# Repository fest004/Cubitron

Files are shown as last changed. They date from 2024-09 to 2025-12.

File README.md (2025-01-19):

```
   ▄█   ▄█▄ ███    █▄  ▀█████████▄     ▄████████ ███▄▄▄▄   
  ███ ▄███▀ ███    ███   ███    ███   ███    ███ ███▀▀▀██▄ 
  ███▐██▀   ███    ███   ███    ███   ███    █▀  ███   ███ 
 ▄█████▀    ███    ███  ▄███▄▄▄██▀   ▄███▄▄▄     ███   ███ 
▀▀█████▄    ███    ███ ▀▀███▀▀▀██▄  ▀▀███▀▀▀     ███   ███ 
  ███▐██▄   ███    ███   ███    ██▄   ███    █▄  ███   ███ 
  ███ ▀███▄ ███    ███   ███    ███   ███    ███ ███   ███ 
  ███   ▀█▀ ████████▀  ▄█████████▀    ██████████  ▀█   █▀  
  ▀                                                        
```
#### You can read about it here: [Link to documentation](https://fest004.github.io/Cubitron/)

#### Folder structure

```
.
├── docs             # Documents (datasheets, references, documentation)
├── hardware         # Hardware design files (CAD)
├── software         # Software files (source files, build files and binaries)
├── LICENSE
└── README.md
```

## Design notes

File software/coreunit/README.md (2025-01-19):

This folder contains the firmware for the main microcontroller

#### Folder structure

```
.
├── docs             # Documents (datasheets, references, documentation)
├── hardware         # Hardware design files (CAD)
├── software         # Software files (source files, build files and binaries)
├── LICENSE
└── README.md
```

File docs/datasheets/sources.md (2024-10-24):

Here is a collection of not datasheets, but external sources/inspiration for some designs.

This github page helped me set up USB-interface with our programmer: 
https://github.com/wagiminator/SAMD-Development-Boards/blob/main/SAMD11D_DevBoard/hardware/SAMD11D_DevBoard_schematic.pdf

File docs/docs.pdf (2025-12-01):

# KUBEN

# 3-Axis Balancing Cube

Hardware Revision 1.0

# 1 • ABOUT THE PROJECT

This document outlines the electrical and mechanical architecture for a 15cm³ self-balancing reaction wheel robot. The system utilizes Model Predictive Control (MPC) or Linear Quadratic Regulation (LQR) to handle the coupled dynamics of three orthogonal axes.

Specs
- Dimensions: 15cm × 15cm × 15cm
- Power Source: 4S LiPo (16.8V Peak)
- Peak Current: 12A (4A per motor)

Key Components
- Compute: ESP32
- Motor Driver: DRV
- Sensor: IMU

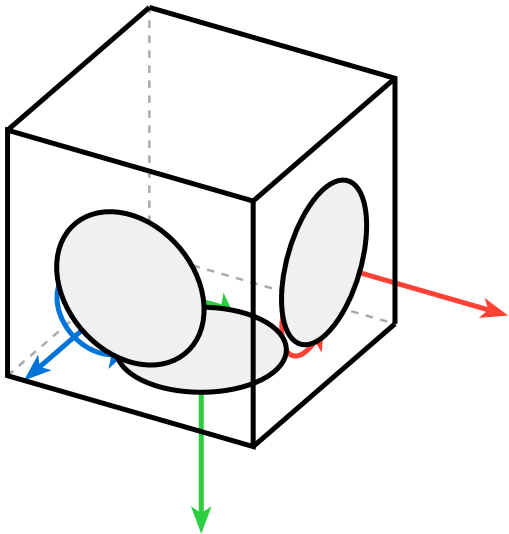
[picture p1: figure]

Figure 1: sketch

# CONTENTS

# 2 • SYSTEM ARCHITECTURE

The system is designed around a centralized controller (ESP32-S3) that manages three motor drivers via SPI and PWM. The control loop runs on a dedicated core to ensure real-time performance for the MPC solver.

## 2.1 • HIGH-LEVEL BLOCK DIAGRAM

- Inputs: IMU (SPI), Encoders (Quadrature), Battery Voltage (ADC).
- Processing: ESP32-S3-WROOM-1 Module.
- Outputs: 3x PWM signals (U, V, W) to Gate Drivers.
- Actuation: 3x BLDC Motors (Gimbal Type) via DRV8316.

DRV8316

DRV8316

DRV8316

MOTOR

MOTOR

MOTOR

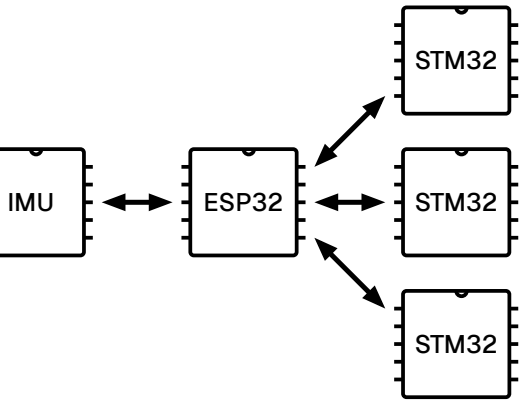
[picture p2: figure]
IMU; ESP32; STM32

Figure 2: block diagram of the controll circuit

# 3 • ELECTRONICS DESIGN

The PCB is a custom 4-layer board designed for high vibration resistance and thermal dissipation.

## 3.1 • MICROCONTROLLER SELECTION

Component: ESP32-S3-WROOM-1-N8R8
- Form Factor: Surface Mount Module (Castellated).
- Reasoning: Through-hole headers fail under reaction wheel vibration. The module provides robust mechanical coupling and optimal center of mass.
- Peripherals Used: - 3x PCNT (Hardware Encoder Counters)
- 2x MCPWM (Motor Control PWM)
- ADC1 (Current Sensing - ADC2 is avoided due to WiFi conflict)

## 3.2 • 3.2. PIN MAPPING (ESP32-S3)

Critical: Do not route current sensing to ADC2. Do not pull strapping pins (GPIO 0, 45, 46) high during boot.

Function | Signal | GPIO | Note
Motor X | PWM U/V/W | 14, 15, 16 | MCPWM Unit 0
| Current Sense | 1 | ADC1_CH0 (Strict requirement)
| Encoder A/B | 38, 39 | PCNT Unit 0
Motor Y | PWM U/V/W | 17, 18, 21 | MCPWM Unit 0
| Current Sense | 2 | ADC1_CH1
| Encoder A/B | 40, 41 | PCNT Unit 1
Motor Z | PWM U/V/W | 35, 36, 37 | MCPWM Unit 1
| Current Sense | 3 | ADC1_CH2
| Encoder A/B | 42, 43 | PCNT Unit 2
Shared | IMU SPI (SCK/MI/MO) | 12, 13, 11 | LSM6DSO Connection
| Driver nSLEEP | 4 | Active High to wake drivers
| Battery Sense | 7 | ADC1_CH6 (Voltage Divider)

Table 1: Master Pin Assignment Table

## 3.3 • 3.3. MOTOR DRIVERS (TI DRV8316)

Variant: DRV8316R (Hardware) or DRV8316T (SPI). SPI is preferred for adjustable gain.
- Current Sensing: The chip has internal Current Sense Amplifiers (CSA) but no internal ADC.
- Wiring Requirement: The SO1, SO2, SO3 pins must be routed to the ESP32 ADC pins listed above.
- Mode: Operate in Current Sense Mode (VREF = 3.3V). Do not use the hardware “Current Limiting Mode” or the torque control will fight the MPC solver.

## 3.4 • 3.4. POWER REGULATION STRATEGY

Direct 16.8V to 3.3V conversion is thermally impossible for the ESP32 load.
1. Stage 1 (Buck): TPS54302 converts 16.8V → 5.0V.
2. Stage 2 (LDO): AMS1117-3.3 converts 5.0V → 3.3V (Clean logic power).

# 4 • 4. SAFETY & PROTECTION CIRCUITS

Reaction wheels generate massive regenerative currents when braking. Protection is mandatory.

## 4.1 • 4.1. REVERSE POLARITY PROTECTION

Component: P-Channel MOSFET (e.g., AO4407).
- Circuit: Gate to GND, Source to Battery+, Drain to System.
- Why: Low voltage drop (<0.1V) compared to diodes, prevents explosion if battery is plugged in backwards.

## 4.2 • 4.2. REGENERATIVE BRAKING CLAMP

Passive: 1000µF 35V Electrolytic Capacitor at the main power entry.
- Active (Optional): If voltage > 18V, a comparator triggers an N-FET to dump energy into a 10Ω, 50W resistor.

## 4.3 • 4.3. BATTERY MANAGEMENT (BMS)

Module: Generic 4S 20A BMS (HX-4S-A01).
- Function: Prevents cell under-voltage (<3.0V) and short circuits.
- Placement: Located between the LiPo battery and the Main PCB.

# 5 • 5. CONTROL THEORY (MPC IMPLEMENTATION)

## 5.1 • 5.1. STATE SPACE MODEL

The robot is modeled as a coupled system. The state vector x contains 9 elements:

### x = [θx

, θy

, θz
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
, ωwx

, ωwy

, ωwz]

T

Where:
- θ: Cube orientation angle (Euler or Quaternion error). •

̇
θ: Angular velocity of the cube (Gyro data).
- ωw: Angular velocity of the reaction wheels (Encoder data).

## 5.2 • 5.2. CONTROL LAW

We utilize an LQR approach for the balancing loop:

### u(t) = −K ⋅ x(t)

Where K is the optimal gain matrix derived from the system physics (Inertia Tensor) and cost matrices Q and R.

## 5.3 • 5.3. SOFTWARE SANDBOX (SAFETY LIMITS)

To prevent MPC instability (hallucinations) from destroying hardware:
- Max Tilt: If |θ| > 20°, Disable_Motors().
- Max Current: Software clamp at 6A per motor.
- Slew Rate: Limit d(Torque)
d

to prevent mechanical jerking.

# 6 • 6. BILL OF MATERIALS (KEY COMPONENTS)

Component | Part Number | Notes
MCU Module | ESP32-S3-WROOM-1 | N8R8 (8MB Flash/PSRAM) recommended.
Motor Driver | TI DRV8316 | Qty: 3. Requires bottom thermal pad vias.
IMU | ST LSM6DSO | SPI Interface. Mount at PCB center.
Buck Converter | TPS54302 | Steps 16V down to 5V.
Protection FET | AO4407 | P-Channel MOSFET for reverse polarity.
Bulk Cap | 1000µF 35V | Low ESR Electrolytic.
Battery | 4S LiPo 650mAh | High C-rating (45C+).

# 7 • 7. NEXT STEPS

1. Simulation: Model the physics in Python/MATLAB to derive the K matrix.
2. Schematic Capture: Implement the pin map in KiCad/EasyEDA.
3. PCB Layout: Focus on thermal vias for DRV8316 and minimizing loop inductance for the capac-itors.

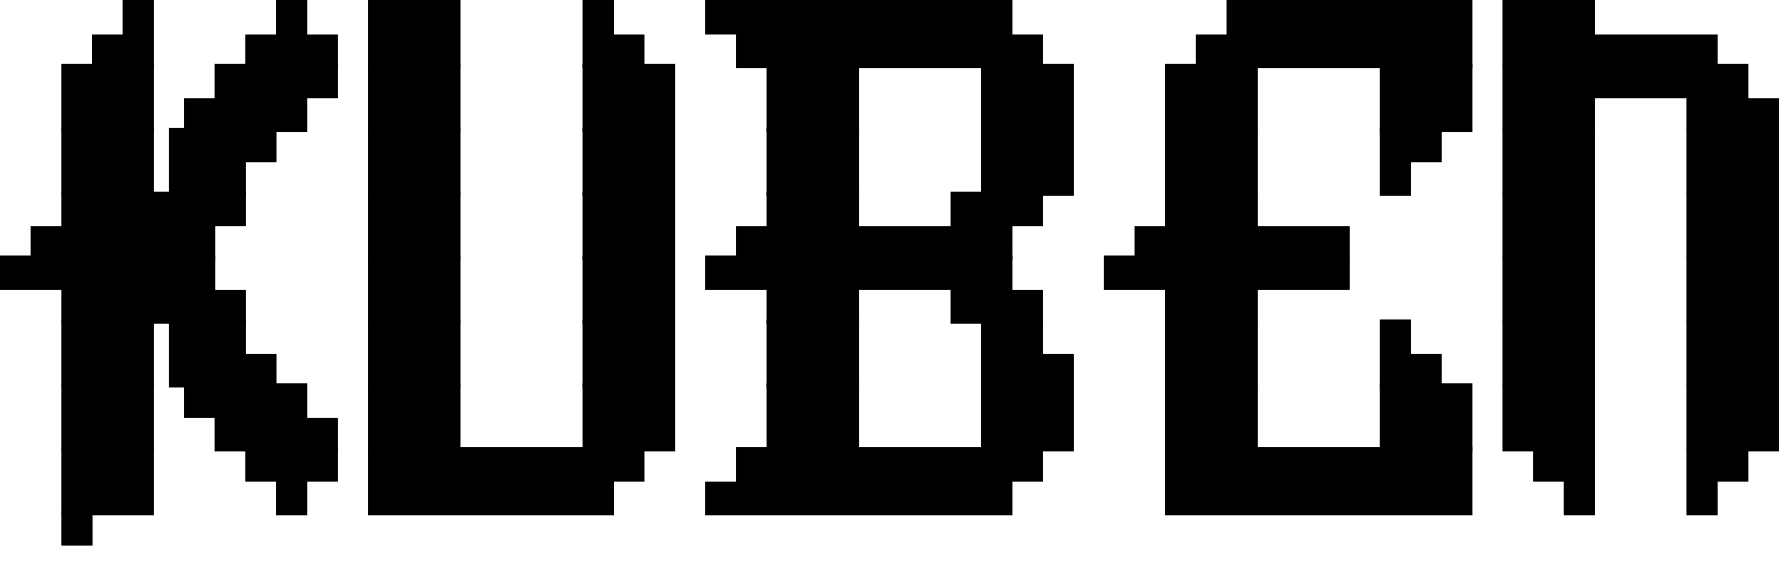
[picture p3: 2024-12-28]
hardware/electronics/core-pcb/kuben.png

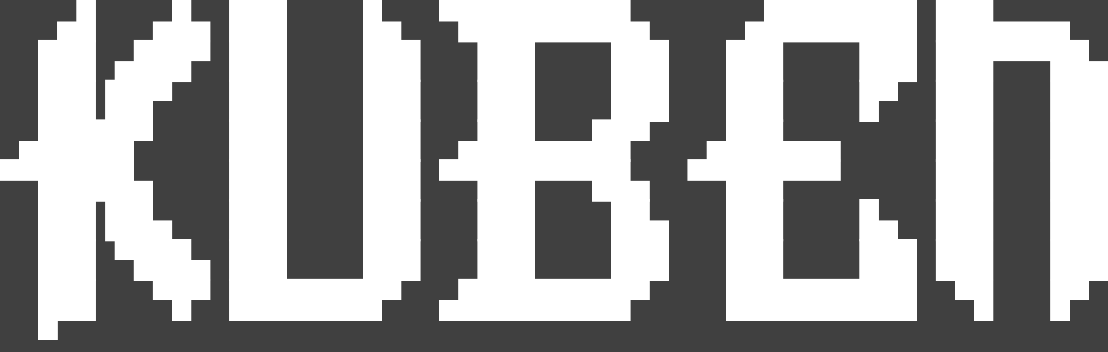
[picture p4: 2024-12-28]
hardware/electronics/core-pcb/kubenhvit.png

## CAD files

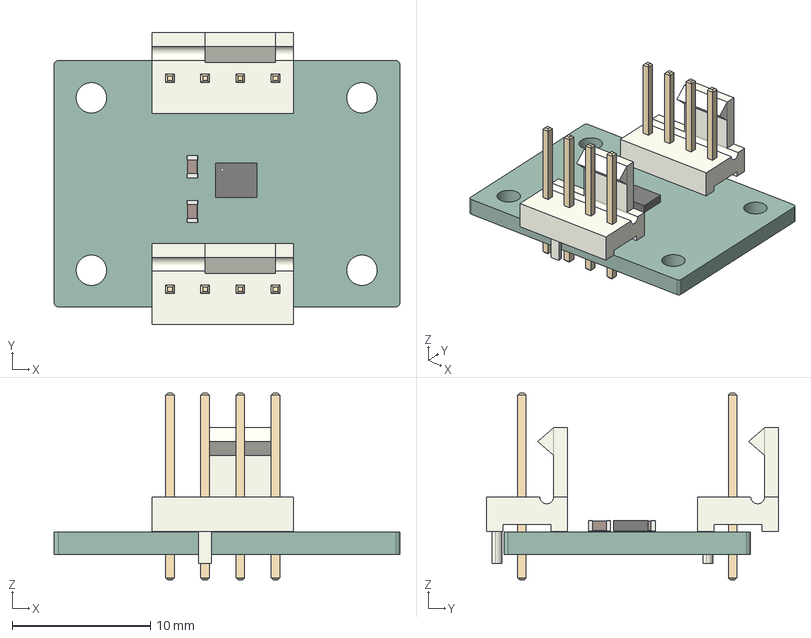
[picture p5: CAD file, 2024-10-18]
hardware/electronics/imu-pcb/imu_IC.step
25.0 x 21.1 x 13.5 mm
C_0603_1608Metric x 2
LGA_14_3x25mm_P05mm_LayoutBorder3x4y
Fan_Pin_Header_Straight_1x04 x 2
imu_IC_PCB

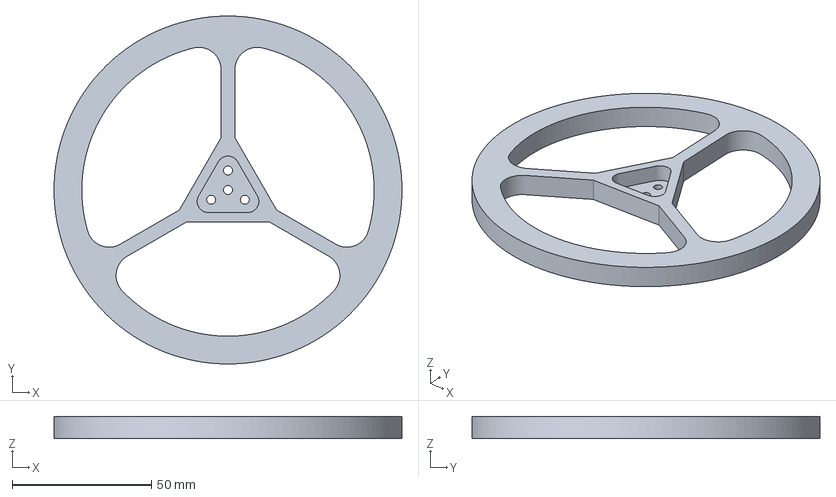
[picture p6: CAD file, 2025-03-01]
hardware/mechanical/tmp/flywheel-Body.3mf
125.0 x 125.0 x 8.00 mm

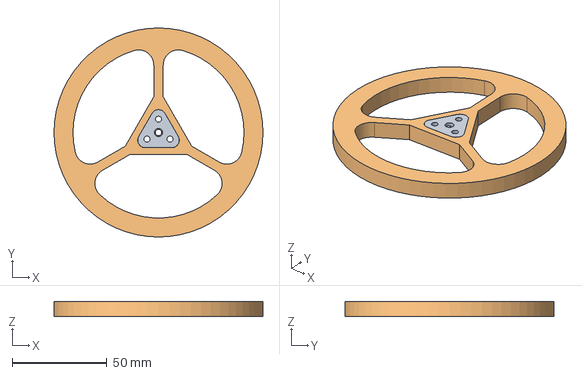
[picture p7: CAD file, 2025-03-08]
hardware/mechanical/flywheel.FCStd
110.0 x 110.0 x 8.00 mm

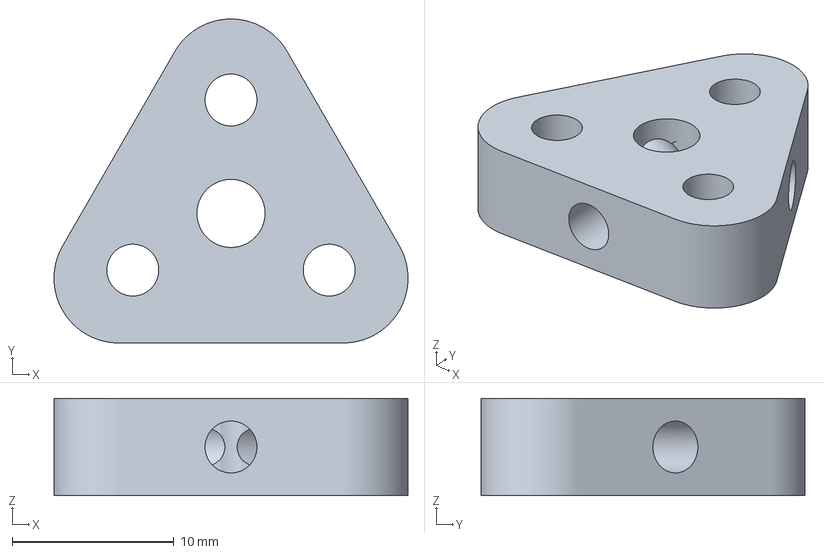
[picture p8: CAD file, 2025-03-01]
hardware/mechanical/tmp/shaft_hub-Body_flat.3mf
21.9 x 20.0 x 6.00 mm

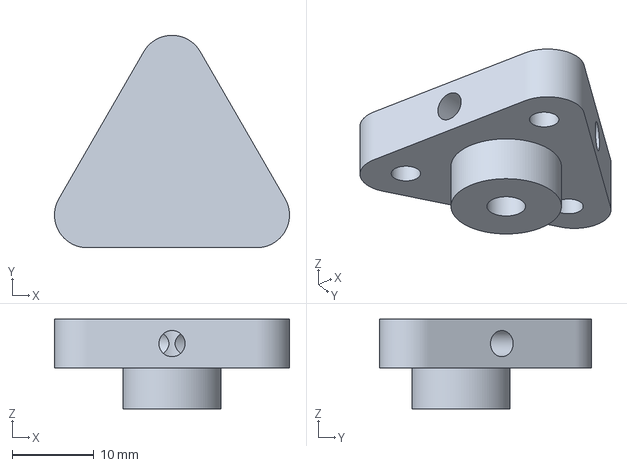
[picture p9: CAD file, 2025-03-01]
hardware/mechanical/tmp/shaft_hub-Body.3mf
28.8 x 26.0 x 11.0 mm

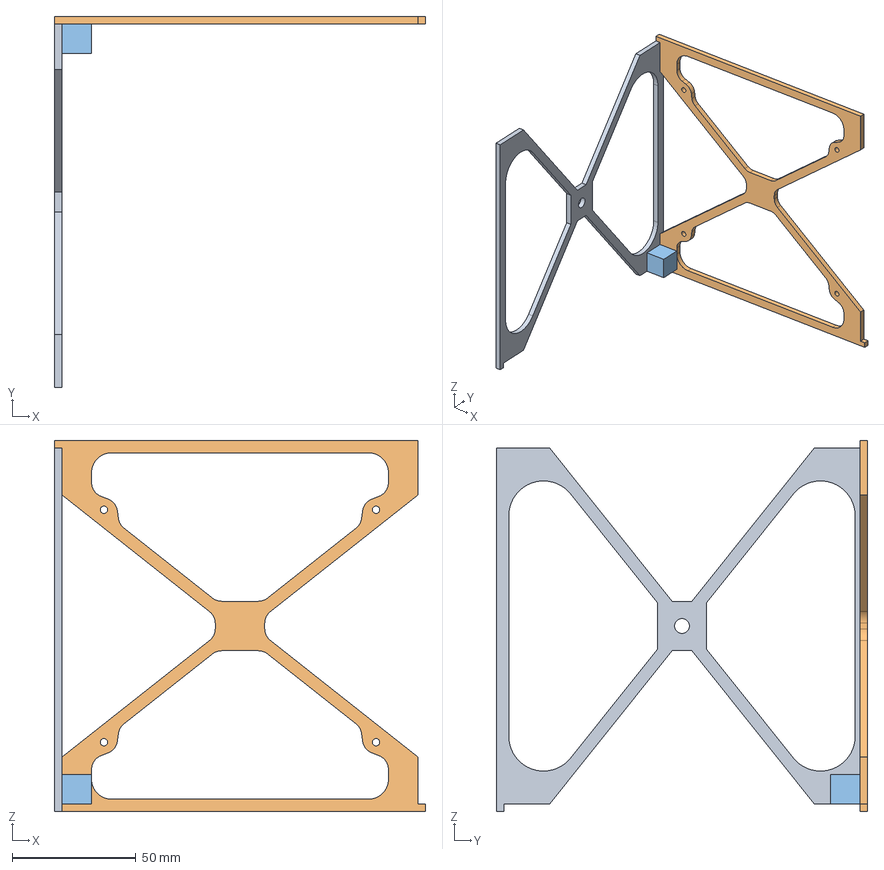
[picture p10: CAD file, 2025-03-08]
hardware/mechanical/cubeshell.FCStd
150.0 x 150.0 x 150.0 mm

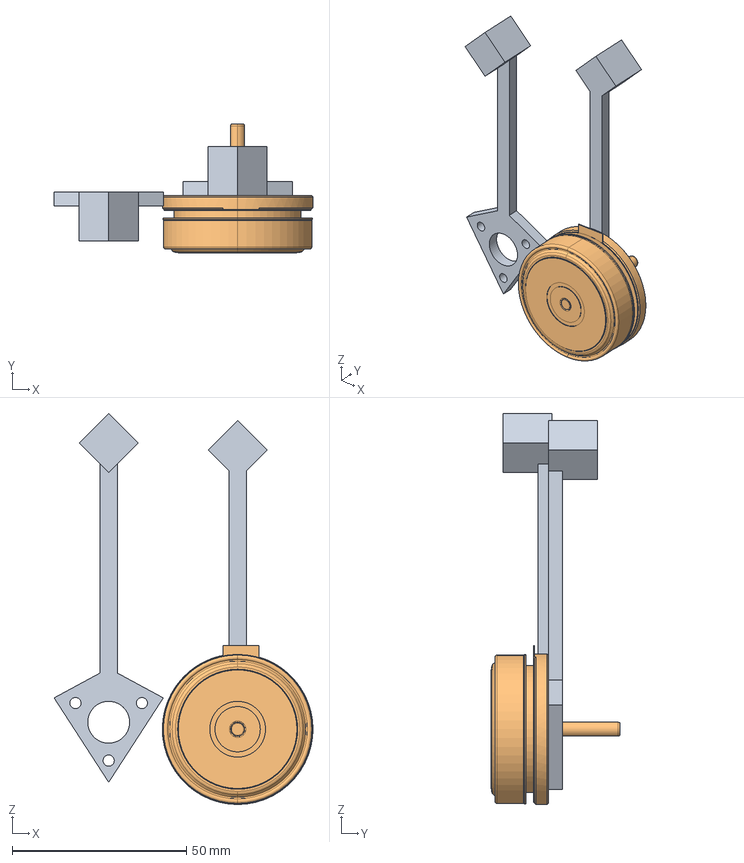
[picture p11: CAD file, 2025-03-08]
hardware/mechanical/motor.FCStd
74.3 x 37.0 x 112.2 mm

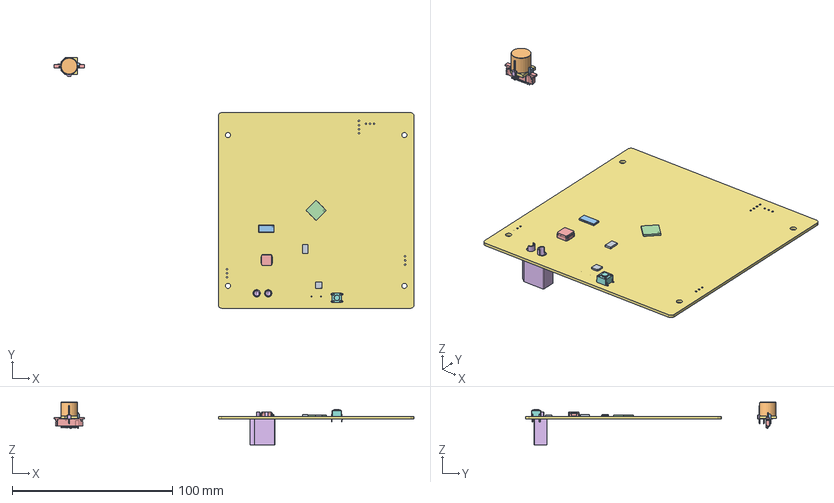
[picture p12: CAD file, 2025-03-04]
hardware/mechanical/motordriverpcb.FCStd
224.5 x 156.2 x 26.6 mm
R_0603_1608Metric
C_0603_1608Metric
IPD70P04P4L08ATMA2
ThermalPin
PinsArrayLR
PinsArrayTB
D_0603_1608Metric
Pins
BODY-TSSOP
LEAD-TSSOP
DAP
SOT-223
TMC4671-LA
SW_PUSH_6mm
ThermalPin001
PinsArrayLR001
PinsArrayTB001
IHLP2525CZER3R3M01
PinHeader_1x03_P2.54mm_Vertical
Base
Pin1Fillet
Pin2Fillet
IPD70P04P4L08ATMA003
59453-052110ECHLF
XT60-M
motordriver_PCB

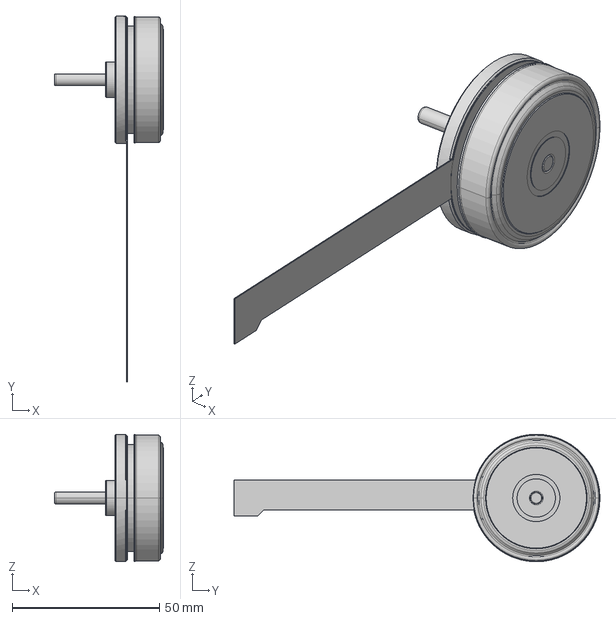
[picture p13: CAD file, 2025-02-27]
hardware/mechanical/tmp/200142_EC45fl_30W_A.stp
37.0 x 124.1 x 43.2 mm

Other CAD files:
hardware/mechanical/assembly.FCStd
hardware/mechanical/kuben-assembly.FCStd

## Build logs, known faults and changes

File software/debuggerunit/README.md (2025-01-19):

This folder contains the firmware for the debugger/programmer

#### Folder structure

```
.
├── docs             # Documents (datasheets, references, documentation)
├── hardware         # Hardware design files (CAD)
├── software         # Software files (source files, build files and binaries)
├── LICENSE
└── README.md
```

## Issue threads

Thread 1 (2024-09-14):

Motor contenders

nammenam, 2024-09-14:
https://www.maxongroup.com/maxon/view/product/397172

fest004, 2024-09-14:
We need:

Torque >= 50mNm
Diameter ~80mm or less
Reasonable power needs (30-50 watt)
Hall sensor or other speed/positional trackers

nammenam, 2024-09-14:
https://www.maxongroup.com/maxon/view/product/397172

nammenam, 2024-09-14:
https://www.maxongroup.com/maxon/view/product/200142

nammenam, 2024-09-17:
options:

https://no.rs-online.com/web/p/dc-motors/2163787

https://no.farnell.com/en-NO/nanotec/df45m024053-a2/bldc-motor-24vdc-6700rpm/dp/2507572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

https://www.ebay.co.uk/itm/225609556846?itemid=225609556846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

Great website for browsing: https://no.rs-online.com/web/

nammenam, 2024-09-20:
https://mechtex.com/products/bldc-motors/bo42-50w

nammenam, 2024-10-12:
@fest004 comment the motor we have decided on and close this issue

fest004, 2024-10-18:
https://www.maxongroup.com/maxon/view/product/200142 This is the motor we have decided on. Waiting to order 3.

fest004, 2024-11-01:
https://no.rs-online.com/web/p/dc-motors/2163794?gb=s is the actual correct motor.

fest004, 2024-11-01:
Closed

nammenam, 2024-11-08:
https://online.flippingbook.com/view/1042987/67/#zoom=true

Closed 2024-11-01.

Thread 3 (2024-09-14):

Make KiCad model for IMU IC

fest004, 2024-09-14:
Supply IMU IC for easy connection and fastening of a tiny IC containing our IMU

fest004, 2024-09-15:
New draft added in commit #dcf342a

Please look over design @nammenam

nammenam, 2024-09-18:
looks good but i hate the headers ngl, might be better to use ffc connection or something. The dimensions are yet to be determined

nammenam, 2024-10-12:
Made this a single pcp thread

nammenam, 2024-10-12:
I am thinking we make an onboard programmer and debugger, I have some ideas on how to do this. I have also experimented with some toolchains so that we dont have to use an ide

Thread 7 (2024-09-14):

Fundraising

nammenam, 2024-09-14:

fest004, 2024-09-17:
More options:

https://no.rs-online.com/web/p/dc-motors/2163787
https://no.farnell.com/en-NO/nanotec/df45m024053-a2/bldc-motor-24vdc-6700rpm/dp/2507572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
https://www.ebay.co.uk/itm/225609556846?itemid=225609556846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

Great website for browsing: https://no.rs-online.com/web/

nammenam, 2024-09-17:
bro hvorfor i alle dager puttet du motorer i fundraising issue

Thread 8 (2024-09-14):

Motor Controller

nammenam, 2024-09-14:
controller ic

https://no.mouser.com/ProductDetail/ADI-Trinamic/TMC4671-LA?qs=TiOZkKH1s2Q5Kur6316zpQ%3D%3D

nammenam, 2024-09-17:
- [ ] Gate driver
- [ ] Current sensor (TMCS1100)
- [ ] MOSFETs driver
- [ ] Voltage regulator?

nammenam, 2024-11-08:
we probably need a bulk capacitor and føyback diodes, I am also a bit worried about the current rating on the mosfets

nammenam, 2024-12-18:
https://no.mouser.com/ProductDetail/Comchip-Technology/CDBU0530?qs=tw%252BuQ%2FB6PO1p1lVxjOIVLQ%3D%3D

diodes for gates and voltage regulator

Closed 2024-11-01.

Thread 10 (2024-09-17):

Batteries

nammenam, 2024-09-17:
Choose what batteries to use

fest004, 2024-10-29:
Did you have a suggestion here?

nammenam, 2024-10-29:
3 or 4 cell lipo or li ion that gives 12v ish. We need a dedicated battery charger since these types of batteries are dangerous

nammenam, 2024-10-29:
https://www.batteriexperten.com/no/artiklar/3s-lic-bang-%26-olufsen,-11.1v,-3400-mah.html?utm_source=google&utm_medium=cpc&utm_campaign=AR%20-%20NO%3A%20PMax%20Shopping%20-%20Low%20%2B%20rest&utm_id=20952393806&gad_source=1&gbraid=0AAAAAD9zpgwSTJq6f4Mc84HNxCjxE0lsf&gclid=Cj0KCQjwj4K5BhDYARIsAD1Ly2qb5FqEXuqrlMG6yx2VeO8Q3zOEVAey9WmoZNo2GKcvyWVWhQknCT0aAtO2EALw_wcB

example

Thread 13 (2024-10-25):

Voltage Regulators & Voltage Ref

fest004, 2024-10-25:
What voltage regulators we need.

fest004, 2024-10-25:
Appropriate regulator for <= 15V down to .2 V, 1.8 V, 2.5 V, 2.85 V, 3.3 V and 5.0 V respectively can be done with this part:

https://eu.mouser.com/ProductDetail/STMicroelectronics/LD1117D33TR?qs=8YYpzd7qSxIl%2FiC6F%2FA2nA%3D%3D

fest004, 2024-10-25:
@nammenam has voltage ref components and voltage regulator for our 30 watt motors. Close issue when added please

fest004, 2024-10-25:
https://eu.mouser.com/ProductDetail/STMicroelectronics/LD1117S33CTR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

This is the correct link for the 12v->3.3v regulator

nammenam, 2024-10-25:
5v ref
https://no.mouser.com/ProductDetail/Texas-Instruments/REF3430TIDBVR?qs=aP1CjGhiNiFUjCaD4YJEpw%3D%3D

fest004, 2024-10-25:
https://eu.mouser.com/ProductDetail/STMicroelectronics/MC34063ECD-TR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

5V to 12V here

nammenam, 2024-10-29:
are we done here? or are we missing something?

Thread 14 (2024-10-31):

Transistors

fest004, 2024-10-31:
Choose transistors for motors

fest004, 2024-10-31:
https://no.mouser.com/ProductDetail/Vishay-Semiconductors/SI4532CDY-T1-GE3?qs=45wPT2wjtGnob1HAmZ9n7g%3D%3D

Dual N and P channel MOSFET transistors.

nammenam, 2024-11-03:
changed the transistors to allow 12v gate voltage, this way we dont have to regulate down to 8V

nammenam, 2024-11-03:
the transistors i added might have too low drain current but there is a version with a larger one we can switch too if it burns up

nammenam, 2024-11-08:
this should really be in #8

Closed 2024-11-08.

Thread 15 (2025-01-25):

ordering components

fest004, 2025-01-25:
[2025_01_06 - 15.53 - MouserBom.xls](https://github.com/user-attachments/files/18547309/2025_01_06.-.15.53.-.MouserBom.xls)

Minimum BOM for Kuben above

nammenam, 2025-01-26:
did you check inductors, they are not in the bom

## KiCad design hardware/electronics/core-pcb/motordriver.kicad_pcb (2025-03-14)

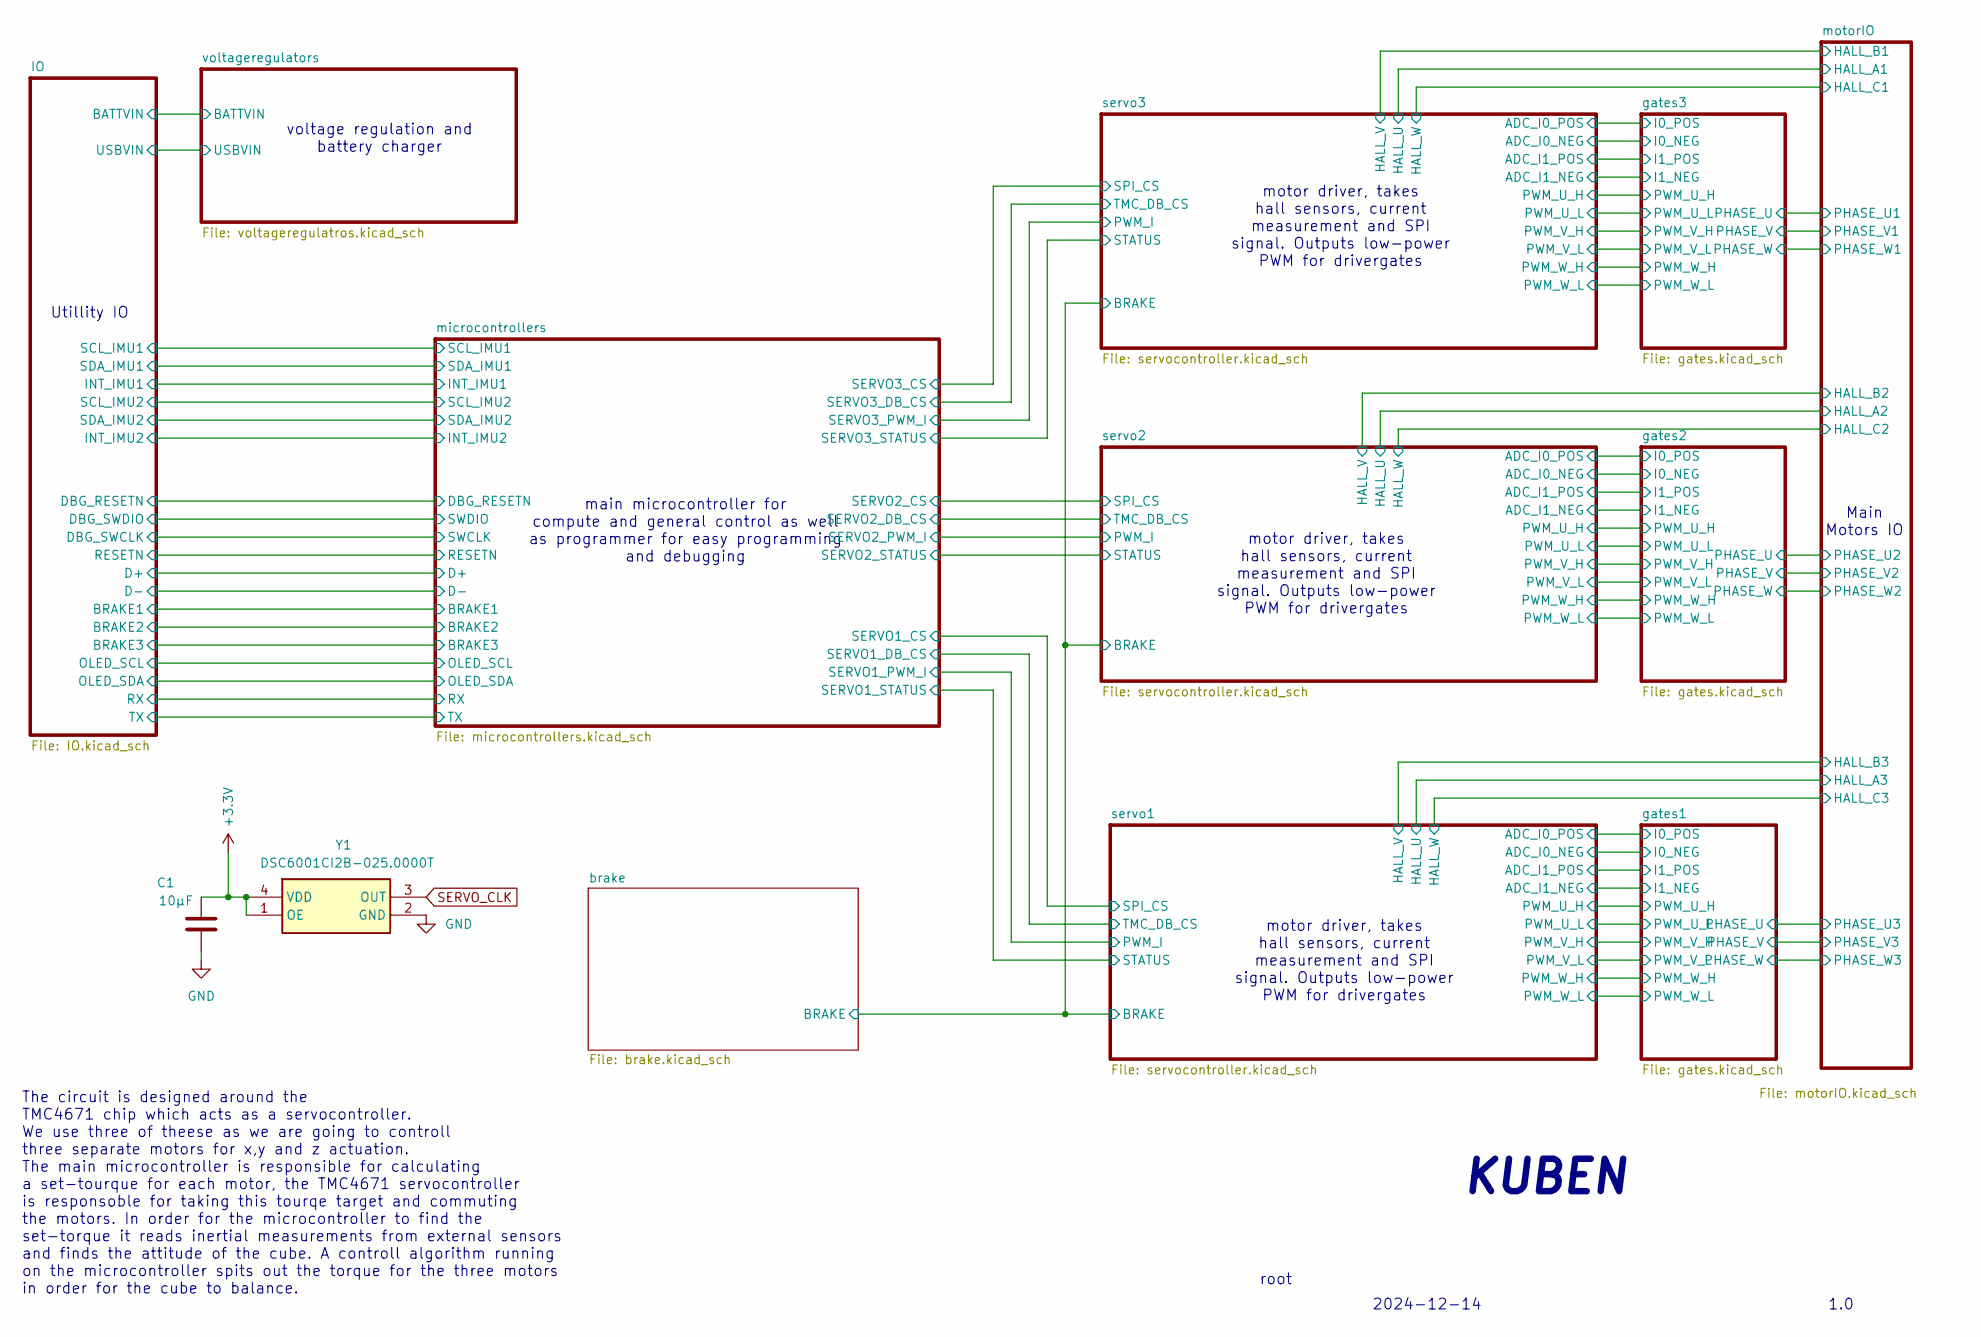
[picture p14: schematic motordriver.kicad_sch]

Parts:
C1: 10µF; C_0603_1608Metric
Y1: DSC6001CI2B-025.0000T; DSC6001CI2B0250000T; Mouser Part Number 579-1CI2B-025.0000T

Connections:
+3.3V: C1.1, Y1.1 (OE), Y1.4 (VDD); also elsewhere on the board
SERVO_CLK: Y1.3 (OUT); also elsewhere on the board

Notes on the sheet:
1.0
voltage regulation and battery charger
motor driver, takes hall sensors, current measurement and SPI signal. Outputs low-power PWM for drivergates
root
Main Motors IO
KUBEN
2024-12-14
main microcontroller for compute and general control as well as programmer for easy programming and debugging
Utillity IO
The circuit is designed around the TMC4671 chip which acts as a servocontroller. We use three of theese as we are going to controll three separate motors for x,y and z actuation. The main microcontroller is responsible for calculating a set-tourque for each motor, the TMC4671 servocontroller is res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

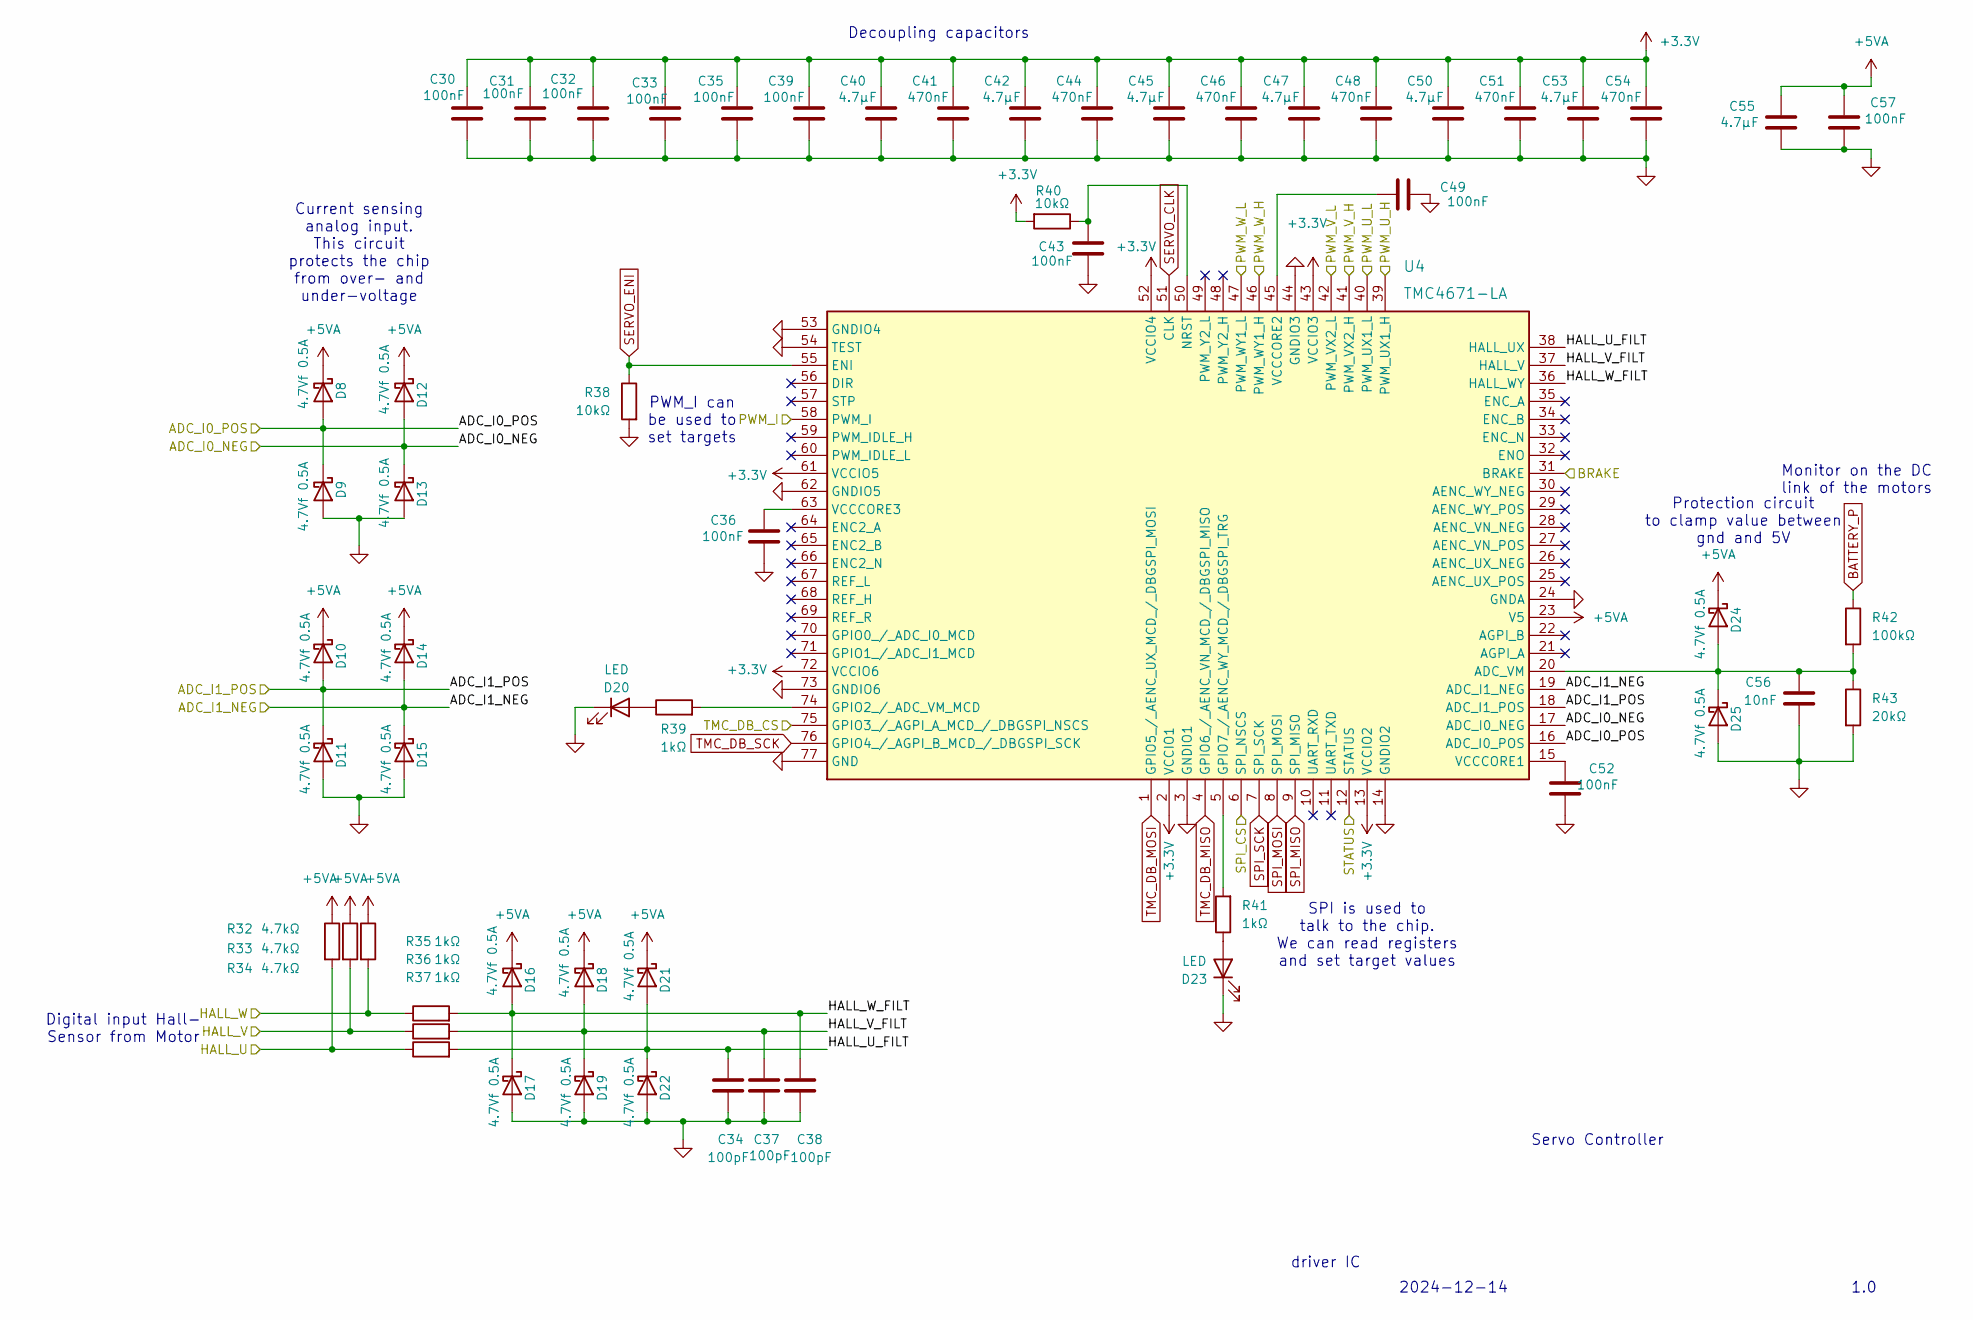
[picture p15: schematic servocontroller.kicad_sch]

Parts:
C30, C31, C32, C33, C35, C36, C39, C43, C49, C52, C57: 100nF; C_0603_1608Metric
C34, C37, C38: 100pF; C_0603_1608Metric
C40, C42, C45, C47, C50, C53, C55: 4.7µF; C_0603_1608Metric
C41, C44, C46, C48, C51, C54: 470nF; C_0603_1608Metric
C56: 10nF; C_0603_1608Metric
D8, D9, D10, D11, D12, D13, D14, D15, D16, D17, D18, D19, D21, D22, D24, D25: 4.7Vf 0.5A; DIOC1709X85N; Mouser Part Number 750-CDBU0520
D20, D23: LED; D_0603_1608Metric
R32, R33, R34: 4.7kΩ; R_0603_1608Metric
R35, R36, R37, R39, R41: 1kΩ; R_0603_1608Metric
R38, R40: 10kΩ; R_0603_1608Metric
R42: 100kΩ; R_0603_1608Metric
R43: 20kΩ; R_0603_1608Metric
U4: TMC4671-LA; QFN40P1050X650X90-77N; Mouser Part Number 700-TMC4671-LA

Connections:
+2.5V: D12.2 (A), D13.1 (K), D14.2 (A), D15.1 (K), U4.17 (ADC_I0_NEG), U4.19 (ADC_I1_NEG); also elsewhere on the board
+3.3V: C30.2, C31.2, C32.2, C33.2, C35.2, C39.2, C40.2, C41.2, C42.2, C44.2, C45.2, C46.2, C47.2, C48.2, C50.2, C51.2, C53.2, C54.2, R40.2, U4.2 (VCCIO1), U4.13 (VCCIO2), U4.43 (VCCIO3), U4.52 (VCCIO4), U4.61 (VCCIO5), U4.72 (VCCIO6); also elsewhere on the board
+5VA: C55.2, C57.2, D8.1 (K), D10.1 (K), D12.1 (K), D14.1 (K), D16.1 (K), D18.1 (K), D21.1 (K), D24.1 (K), R32.1, R33.1, R34.1, U4.23 (V5); also elsewhere on the board
/brake/BRAKE: U4.31 (BRAKE); also elsewhere on the board
/gates1/PWM_U_H: U4.39 (PWM_UX1_H); also elsewhere on the board
/gates1/PWM_U_L: U4.40 (PWM_UX1_L); also elsewhere on the board
/gates1/PWM_V_H: U4.41 (PWM_VX2_H); also elsewhere on the board
/gates1/PWM_V_L: U4.42 (PWM_VX2_L); also elsewhere on the board
/gates1/PWM_W_H: U4.46 (PWM_WY1_H); also elsewhere on the board
/gates1/PWM_W_L: U4.47 (PWM_WY1_L); also elsewhere on the board
/microcontrollers/SERVO1_CS: U4.6 (SPI_NSCS); also elsewhere on the board
/microcontrollers/SERVO1_DB_CS: U4.75 (GPIO3_/_AGPI_A_MCD_/_DBGSPI_NSCS); also elsewhere on the board
/microcontrollers/SERVO1_PWM_I: U4.58 (PWM_I); also elsewhere on the board
/microcontrollers/SERVO1_STATUS: U4.12 (STATUS); also elsewhere on the board
/motorIO/HALL_A3: R32.2, R37.1; also elsewhere on the board
/motorIO/HALL_B3: R33.2, R36.1; also elsewhere on the board
/motorIO/HALL_C3: R34.2, R35.1; also elsewhere on the board
/servo1/ADC_I0_POS: D8.2 (A), D9.1 (K), U4.16 (ADC_I0_POS); also elsewhere on the board
/servo1/ADC_I1_POS: D10.2 (A), D11.1 (K), U4.18 (ADC_I1_POS); also elsewhere on the board
/servo1/HALL_U_FILT: C34.2, D21.2 (A), D22.1 (K), R37.2, U4.38 (HALL_UX); also elsewhere on the board
/servo1/HALL_V_FILT: C37.2, D18.2 (A), D19.1 (K), R36.2, U4.37 (HALL_V); also elsewhere on the board
/servo1/HALL_W_FILT: C38.2, D16.2 (A), D17.1 (K), R35.2, U4.36 (HALL_WY); also elsewhere on the board
BATTERY_P: R42.1; also elsewhere on the board
unnamed 112: D20.2 (A), R39.1; also elsewhere on the board
unnamed: D23.2 (A), R41.1
unnamed: C56.2, D24.2 (A), D25.1 (K), R42.2, R43.1, U4.20 (ADC_VM)
unnamed 211: R39.2, U4.74 (GPIO2_/_ADC_VM_MCD); also elsewhere on the board
unnamed: R41.2, U4.5 (GPIO7_/_AENC_WY_MCD_/_DBGSPI_TRG)
unnamed: C43.1, R40.1, U4.50 (NRST)
unnamed: C52.2, U4.15 (VCCCORE1)
unnamed: C49.2, U4.45 (VCCCORE2)
unnamed 216: C36.2, U4.63 (VCCCORE3); also elsewhere on the board
SERVO_CLK: U4.51 (CLK); also elsewhere on the board
SERVO_ENI: R38.1, U4.55 (ENI); also elsewhere on the board
SPI_MISO: U4.9 (SPI_MISO); also elsewhere on the board
SPI_MOSI: U4.8 (SPI_MOSI); also elsewhere on the board
SPI_SCK: U4.7 (SPI_SCK); also elsewhere on the board
TMC_DB_MISO: U4.4 (GPIO6_/_AENC_VN_MCD_/_DBGSPI_MISO); also elsewhere on the board
TMC_DB_MOSI: U4.1 (GPIO5_/_AENC_UX_MCD_/_DBGSPI_MOSI); also elsewhere on the board
TMC_DB_SCK: U4.76 (GPIO4_/_AGPI_B_MCD_/_DBGSPI_SCK); also elsewhere on the board

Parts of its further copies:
C74, C75, C76, C77, C79, C80, C83, C87, C93, C96, C101, C111, C112, C113, C114, C116, C117, C120, C124, C130, C133, C138: 100nF; C_0603_1608Metric
C78, C81, C82, C115, C118, C119: 100pF; C_0603_1608Metric
C84, C86, C89, C91, C94, C97, C99, C121, C123, C126, C128, C131, C134, C136: 4.7µF; C_0603_1608Metric
C85, C88, C90, C92, C95, C98, C122, C125, C127, C129, C132, C135: 470nF; C_0603_1608Metric
C100, C137: 10nF; C_0603_1608Metric
D33, D34, D35, D36, D37, D38, D39, D40, D41, D42, D43, D44, D46, D47, D49, D50, D55, D56, D57, D58, D59, D60, D61, D62, D63, D64, D65, D66, D68, D69, D71, D72: 4.7Vf 0.5A; DIOC1709X85N; Mouser Part Number 750-CDBU0520
D45, D48, D67, D70: LED; D_0603_1608Metric
R52, R53, R54, R77, R78, R79: 4.7kΩ; R_0603_1608Metric
R55, R56, R57, R59, R61, R80, R81, R82, R84, R86: 1kΩ; R_0603_1608Metric
R58, R60, R83, R85: 10kΩ; R_0603_1608Metric
R62, R87: 100kΩ; R_0603_1608Metric
R63, R88: 20kΩ; R_0603_1608Metric
U6, U7: TMC4671-LA; QFN40P1050X650X90-77N; Mouser Part Number 700-TMC4671-LA

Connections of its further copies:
+2.5V: D37.2 (A), D38.1 (K), D39.2 (A), D40.1 (K), D59.2 (A), D60.1 (K), D61.2 (A), D62.1 (K), U6.17 (ADC_I0_NEG), U6.19 (ADC_I1_NEG), U7.17 (ADC_I0_NEG), U7.19 (ADC_I1_NEG); also elsewhere on the board
+3.3V: C74.2, C75.2, C76.2, C77.2, C79.2, C83.2, C84.2, C85.2, C86.2, C88.2, C89.2, C90.2, C91.2, C92.2, C94.2, C95.2, C97.2, C98.2, C111.2, C112.2, C113.2, C114.2, C116.2, C120.2, C121.2, C122.2, C123.2, C125.2, C126.2, C127.2, C128.2, C129.2, C131.2, C132.2, C134.2, C135.2, R60.2, R85.2, U6.2 (VCCIO1), U6.13 (VCCIO2), U6.43 (VCCIO3), U6.52 (VCCIO4), U6.61 (VCCIO5), U6.72 (VCCIO6), U7.2 (VCCIO1), U7.13 (VCCIO2), U7.43 (VCCIO3), U7.52 (VCCIO4), U7.61 (VCCIO5), U7.72 (VCCIO6); also elsewhere on the board
+5VA: C99.2, C101.2, C136.2, C138.2, D33.1 (K), D35.1 (K), D37.1 (K), D39.1 (K), D41.1 (K), D43.1 (K), D46.1 (K), D49.1 (K), D55.1 (K), D57.1 (K), D59.1 (K), D61.1 (K), D63.1 (K), D65.1 (K), D68.1 (K), D71.1 (K), R52.1, R53.1, R54.1, R77.1, R78.1, R79.1, U6.23 (V5), U7.23 (V5); also elsewhere on the board
/brake/BRAKE: U6.31 (BRAKE), U7.31 (BRAKE); also elsewhere on the board
/gates2/PWM_U_H: U6.39 (PWM_UX1_H); also elsewhere on the board
/gates2/PWM_U_L: U6.40 (PWM_UX1_L); also elsewhere on the board
/gates2/PWM_V_H: U6.41 (PWM_VX2_H); also elsewhere on the board
/gates2/PWM_V_L: U6.42 (PWM_VX2_L); also elsewhere on the board
/gates2/PWM_W_H: U6.46 (PWM_WY1_H); also elsewhere on the board
/gates2/PWM_W_L: U6.47 (PWM_WY1_L); also elsewhere on the board
/gates3/PWM_U_H: U7.39 (PWM_UX1_H); also elsewhere on the board
/gates3/PWM_U_L: U7.40 (PWM_UX1_L); also elsewhere on the board
/gates3/PWM_V_H: U7.41 (PWM_VX2_H); also elsewhere on the board
/gates3/PWM_V_L: U7.42 (PWM_VX2_L); also elsewhere on the board
/gates3/PWM_W_H: U7.46 (PWM_WY1_H); also elsewhere on the board
/gates3/PWM_W_L: U7.47 (PWM_WY1_L); also elsewhere on the board
/microcontrollers/SERVO2_CS: U6.6 (SPI_NSCS); also elsewhere on the board
/microcontrollers/SERVO2_DB_CS: U6.75 (GPIO3_/_AGPI_A_MCD_/_DBGSPI_NSCS); also elsewhere on the board
/microcontrollers/SERVO2_PWM_I: U6.58 (PWM_I); also elsewhere on the board
/microcontrollers/SERVO2_STATUS: U6.12 (STATUS); also elsewhere on the board
/microcontrollers/SERVO3_CS: U7.6 (SPI_NSCS); also elsewhere on the board
/microcontrollers/SERVO3_DB_CS: U7.75 (GPIO3_/_AGPI_A_MCD_/_DBGSPI_NSCS); also elsewhere on the board
/microcontrollers/SERVO3_PWM_I: U7.58 (PWM_I); also elsewhere on the board
/microcontrollers/SERVO3_STATUS: U7.12 (STATUS); also elsewhere on the board
/motorIO/HALL_A1: R77.2, R82.1; also elsewhere on the board
/motorIO/HALL_A2: R52.2, R57.1; also elsewhere on the board
/motorIO/HALL_B1: R78.2, R81.1; also elsewhere on the board
/motorIO/HALL_B2: R53.2, R56.1; also elsewhere on the board
/motorIO/HALL_C1: R79.2, R80.1; also elsewhere on the board
/motorIO/HALL_C2: R54.2, R55.1; also elsewhere on the board
/servo2/ADC_I0_POS: D33.2 (A), D34.1 (K), U6.16 (ADC_I0_POS); also elsewhere on the board
/servo2/ADC_I1_POS: D35.2 (A), D36.1 (K), U6.18 (ADC_I1_POS); also elsewhere on the board
/servo2/HALL_U_FILT: C78.2, D46.2 (A), D47.1 (K), R57.2, U6.38 (HALL_UX)
/servo2/HALL_V_FILT: C81.2, D43.2 (A), D44.1 (K), R56.2, U6.37 (HALL_V)
/servo2/HALL_W_FILT: C82.2, D41.2 (A), D42.1 (K), R55.2, U6.36 (HALL_WY)
/servo3/ADC_I0_POS: D55.2 (A), D56.1 (K), U7.16 (ADC_I0_POS); also elsewhere on the board
/servo3/ADC_I1_POS: D57.2 (A), D58.1 (K), U7.18 (ADC_I1_POS); also elsewhere on the board
/servo3/HALL_U_FILT: C115.2, D68.2 (A), D69.1 (K), R82.2, U7.38 (HALL_UX)
/servo3/HALL_V_FILT: C118.2, D65.2 (A), D66.1 (K), R81.2, U7.37 (HALL_V)
/servo3/HALL_W_FILT: C119.2, D63.2 (A), D64.1 (K), R80.2, U7.36 (HALL_WY)
BATTERY_P: R62.1, R87.1; also elsewhere on the board
unnamed: D45.2 (A), R59.1
unnamed: D48.2 (A), R61.1
unnamed: C100.2, D49.2 (A), D50.1 (K), R62.2, R63.1, U6.20 (ADC_VM)
unnamed: D67.2 (A), R84.1
unnamed: D70.2 (A), R86.1
unnamed: C137.2, D71.2 (A), D72.1 (K), R87.2, R88.1, U7.20 (ADC_VM)
unnamed: R59.2, U6.74 (GPIO2_/_ADC_VM_MCD)
unnamed: R61.2, U6.5 (GPIO7_/_AENC_WY_MCD_/_DBGSPI_TRG)
unnamed 221: C87.1, R60.1, U6.50 (NRST); also elsewhere on the board
unnamed: C96.2, U6.15 (VCCCORE1)
unnamed: C93.2, U6.45 (VCCCORE2)
unnamed: C80.2, U6.63 (VCCCORE3)
unnamed: R84.2, U7.74 (GPIO2_/_ADC_VM_MCD)
unnamed: R86.2, U7.5 (GPIO7_/_AENC_WY_MCD_/_DBGSPI_TRG)
unnamed: C124.1, R85.1, U7.50 (NRST)
unnamed: C133.2, U7.15 (VCCCORE1)
unnamed: C130.2, U7.45 (VCCCORE2)
unnamed: C117.2, U7.63 (VCCCORE3)
SERVO_CLK: U6.51 (CLK), U7.51 (CLK); also elsewhere on the board
SERVO_ENI: R58.1, R83.1, U6.55 (ENI), U7.55 (ENI); also elsewhere on the board
SPI_MISO: U6.9 (SPI_MISO), U7.9 (SPI_MISO); also elsewhere on the board
SPI_MOSI: U6.8 (SPI_MOSI), U7.8 (SPI_MOSI); also elsewhere on the board
SPI_SCK: U6.7 (SPI_SCK), U7.7 (SPI_SCK); also elsewhere on the board
TMC_DB_MISO: U6.4 (GPIO6_/_AENC_VN_MCD_/_DBGSPI_MISO), U7.4 (GPIO6_/_AENC_VN_MCD_/_DBGSPI_MISO); also elsewhere on the board
TMC_DB_MOSI: U6.1 (GPIO5_/_AENC_UX_MCD_/_DBGSPI_MOSI), U7.1 (GPIO5_/_AENC_UX_MCD_/_DBGSPI_MOSI); also elsewhere on the board
TMC_DB_SCK: U6.76 (GPIO4_/_AGPI_B_MCD_/_DBGSPI_SCK), U7.76 (GPIO4_/_AGPI_B_MCD_/_DBGSPI_SCK); also elsewhere on the board

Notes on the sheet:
Monitor on the DC link of the motors
Servo Controller
driver IC
Current sensing analog input. This circuit protects the chip from over- and under-voltage
Decoupling capacitors
2024-12-14
Protection circuit to clamp value between gnd and 5V
SPI is used to talk to the chip. We can read registers and set target values
1.0
PWM_I can be used to set targets
Digital input Hall- Sensor from Motor

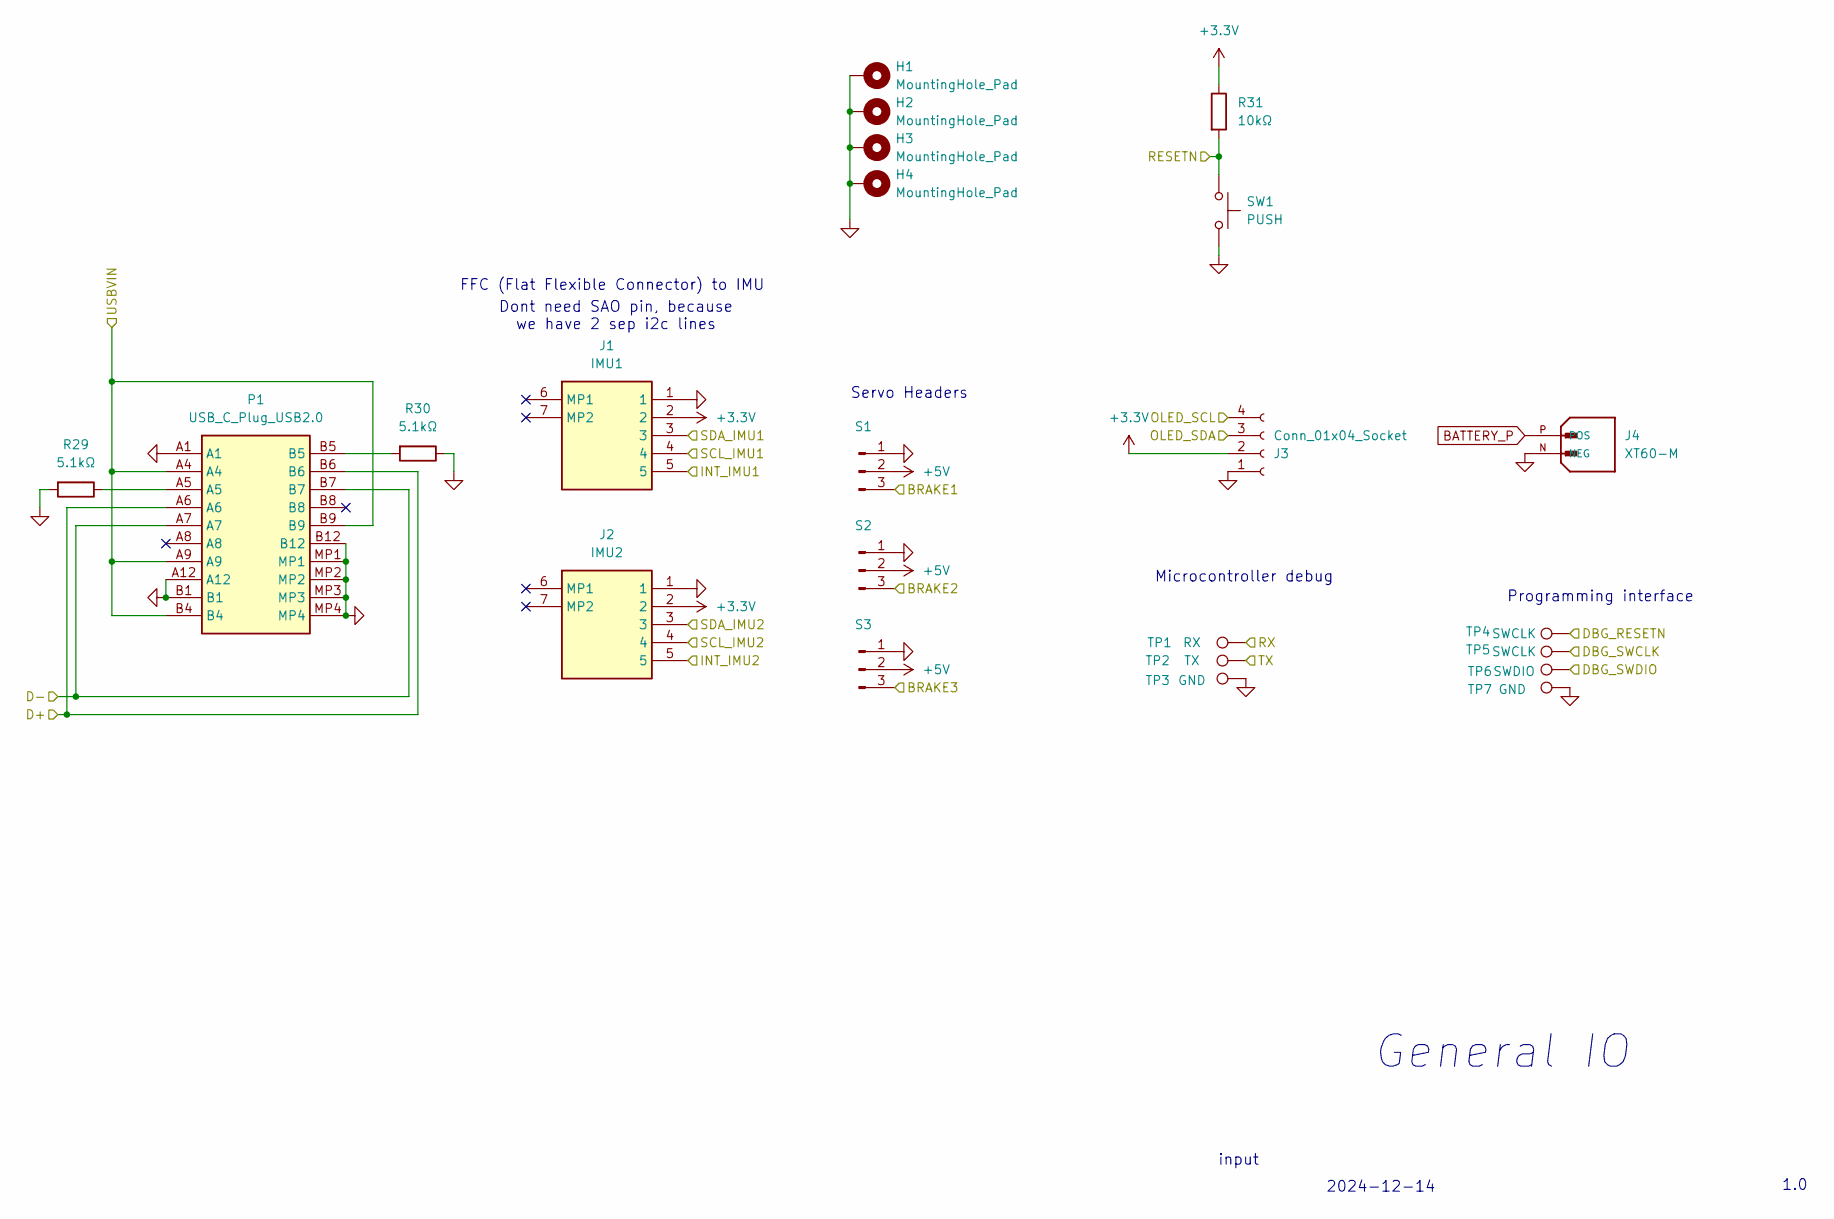
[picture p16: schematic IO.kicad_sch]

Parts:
H1, H2, H3, H4: MountingHole_Pad; MountingHole_3.2mm_M3_DIN965_Pad
J1: IMU1; 59453052110ECHLF; Manufacturer_Part_Number 59453-052110ECHLF
J2: IMU2; 59453052110ECHLF; Manufacturer_Part_Number 59453-052110ECHLF
J3: Conn_01x04_Socket; PinSocket_1x04_P2.54mm_Vertical
J4: XT60-M; AMASS_XT60-M; PARTREV V1.2
P1: USB_C_Plug_USB2.0; USB4110GFA; Mouser Part Number 640-USB4110-GF-A
R29, R30: 5.1kΩ; R_0603_1608Metric
R31: 10kΩ; R_0603_1608Metric
S1, S2, S3: PinHeader_1x03_P2.54mm_Vertical
SW1: PUSH; SW_PUSH_6mm
TP1: RX; TestPoint_Pad_D1.5mm
TP2: TX; TestPoint_Pad_D1.5mm
TP3, TP7: GND; TestPoint_Pad_D1.5mm
TP4, TP5: SWCLK; TestPoint_Pad_D1.5mm
TP6: SWDIO; TestPoint_Pad_D1.5mm

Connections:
+3.3V: J1.2, J2.2, J3.2, R31.1; also elsewhere on the board
+5V: S1.2, S2.2, S3.2
/IO/BRAKE1: S1.3; also elsewhere on the board
/IO/BRAKE2: S2.3; also elsewhere on the board
/IO/BRAKE3: S3.3; also elsewhere on the board
/IO/D+: P1.A6, P1.B6; also elsewhere on the board
/IO/D-: P1.A7, P1.B7; also elsewhere on the board
/IO/DBG_RESETN: TP4.1; also elsewhere on the board
/IO/DBG_SWCLK: TP5.1; also elsewhere on the board
/IO/DBG_SWDIO: TP6.1; also elsewhere on the board
/IO/INT_IMU1: J1.5; also elsewhere on the board
/IO/INT_IMU2: J2.5; also elsewhere on the board
/IO/OLED_SCL: J3.4; also elsewhere on the board
/IO/OLED_SDA: J3.3; also elsewhere on the board
/IO/RX: TP1.1; also elsewhere on the board
/IO/SCL_IMU1: J1.4; also elsewhere on the board
/IO/SCL_IMU2: J2.4; also elsewhere on the board
/IO/SDA_IMU1: J1.3; also elsewhere on the board
/IO/SDA_IMU2: J2.3; also elsewhere on the board
/IO/TX: TP2.1; also elsewhere on the board
/IO/USBVIN: P1.A4, P1.A9, P1.B4, P1.B9; also elsewhere on the board
/microcontrollers/RESETN: R31.2, SW1.1; also elsewhere on the board
BATTERY_P: J4.P (POS); also elsewhere on the board
unnamed: P1.A5, R29.1
unnamed 188: P1.B5, R30.2; also elsewhere on the board

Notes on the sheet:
input
Dont need SAO pin, because we have 2 sep i2c lines
General IO
FFC (Flat Flexible Connector) to IMU
Programming interface
Microcontroller debug
Servo Headers
2024-12-14
1.0

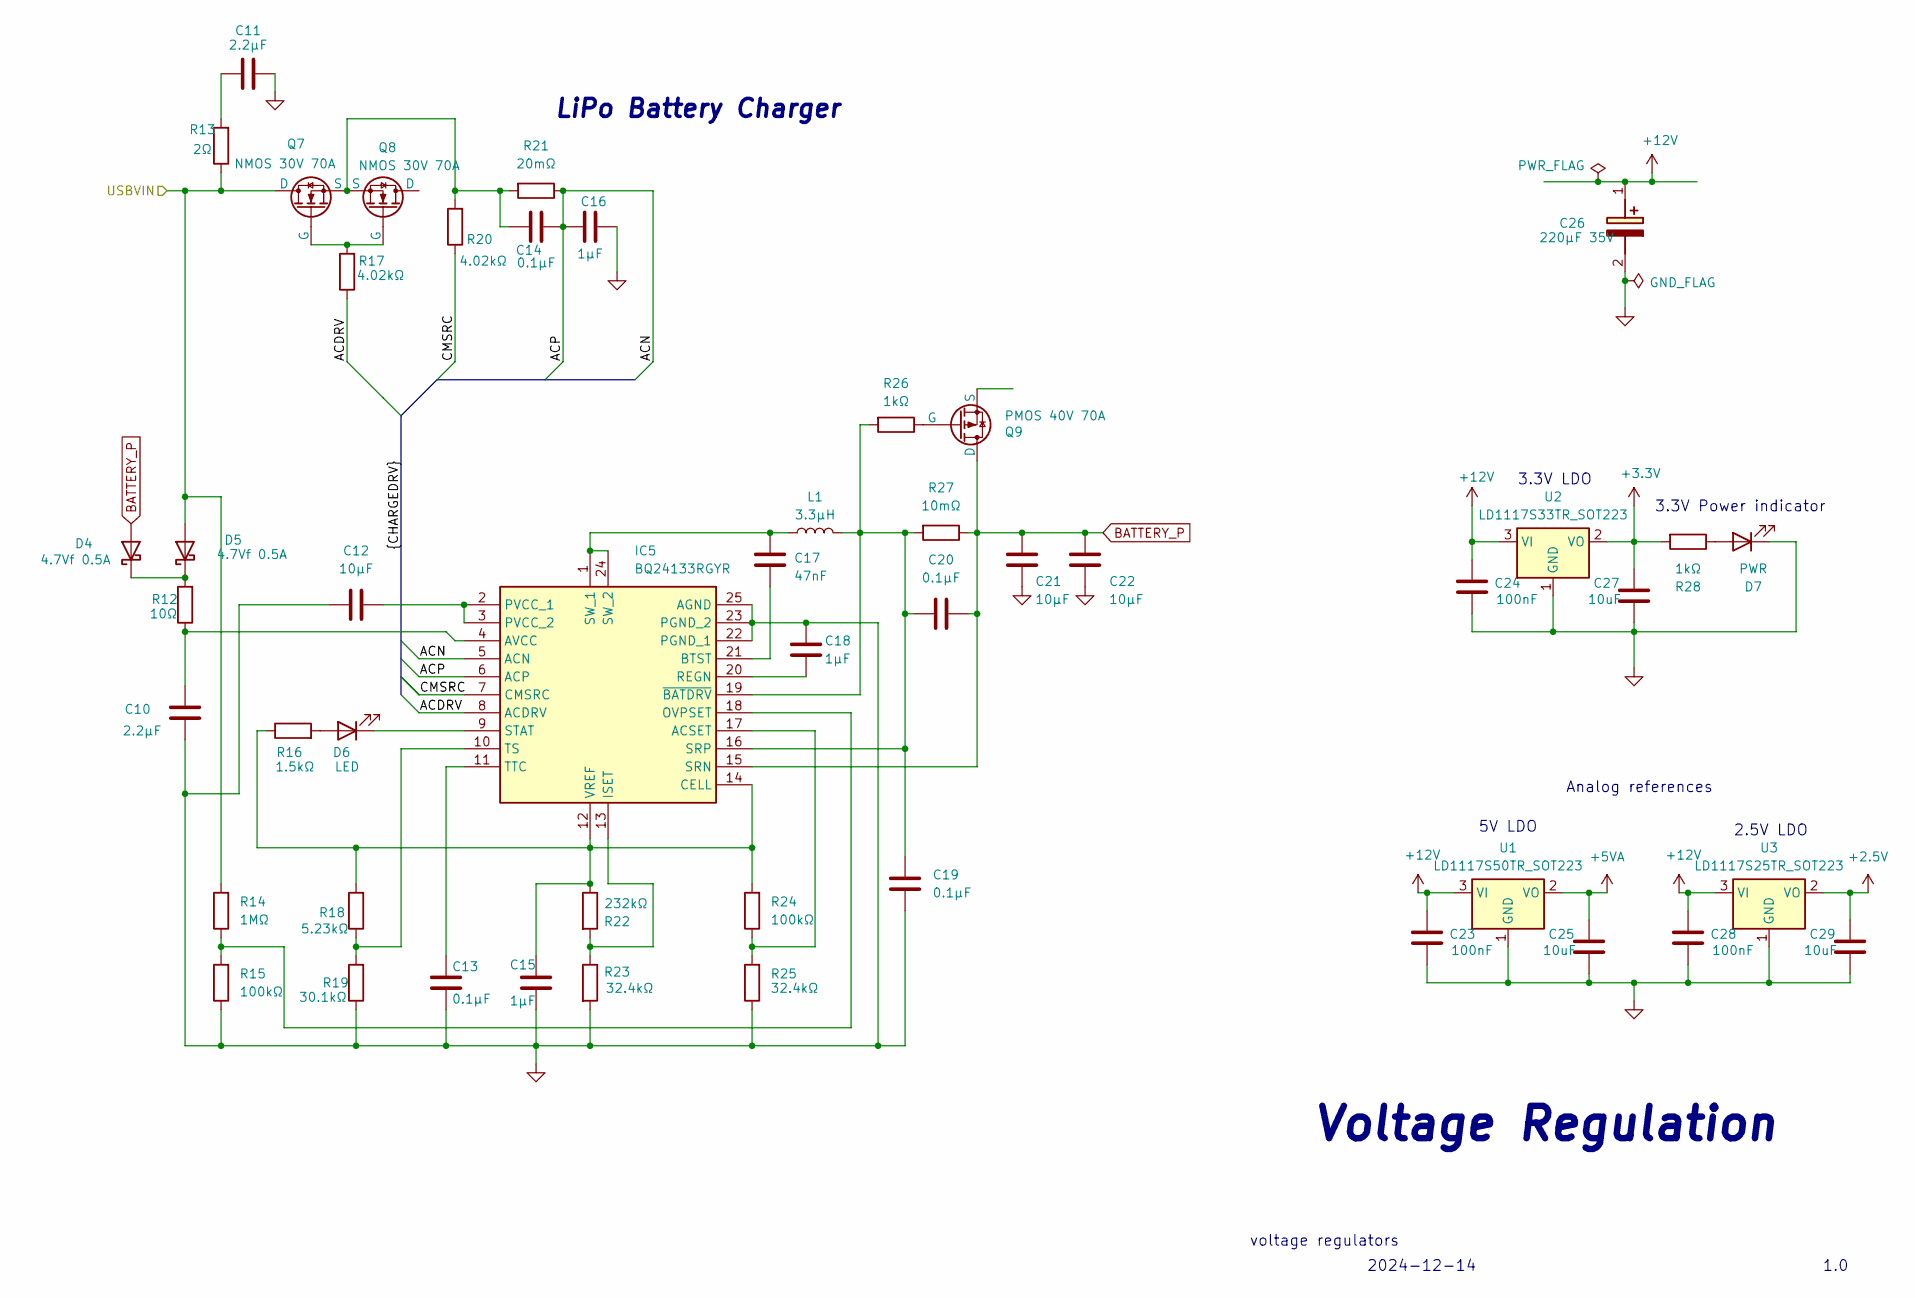
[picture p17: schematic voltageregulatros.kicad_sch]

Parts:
C10, C11: 2.2µF; C_0603_1608Metric
C12, C21, C22: 10µF; C_0603_1608Metric
C13, C14, C19, C20: 0.1µF; C_0603_1608Metric
C15, C16, C18: 1µF; C_0603_1608Metric
C17: 47nF; C_0603_1608Metric
C23, C24, C28: 100nF; C_0603_1608Metric
C25, C27, C29: 10uF; C_0603_1608Metric
C26: 220µF 35V; CAPAE1050X1050N; Mouser Part Number 594-MAL215099001E3
D4, D5: 4.7Vf 0.5A; DIOC1709X85N; Mouser Part Number 750-CDBU0520
D6: LED; D_0603_1608Metric
D7: PWR; D_0603_1608Metric
IC5: BQ24133RGYR; Mouser Part Number 595-BQ24133RGYR
L1: 3.3µH; INDPM6965X300N; Mouser Part Number 70-IHLP2525CZER3R3M0
Q7, Q8: NMOS 30V 70A; IPD047N03LF2SATMA1
Q9: PMOS 40V 70A; IPD70P04P4L08ATMA2
R12: 10Ω; R_0603_1608Metric
R13: 2Ω; R_0603_1608Metric
R14: 1MΩ; R_0603_1608Metric
R15, R24: 100kΩ; R_0603_1608Metric
R16: 1.5kΩ; R_0603_1608Metric
R17, R20: 4.02kΩ; R_0603_1608Metric
R18: 5.23kΩ; R_0603_1608Metric
R19: 30.1kΩ; R_0603_1608Metric
R21: 20mΩ; R_0603_1608Metric
R22: 232kΩ; R_0603_1608Metric
R23, R25: 32.4kΩ; R_0603_1608Metric
R26, R28: 1kΩ; R_0603_1608Metric
R27: 10mΩ; R_0603_1608Metric
U1: LD1117S50TR_SOT223; SOT-223-3_TabPin2
U2: LD1117S33TR_SOT223; SOT-223-3_TabPin2
U3: LD1117S25TR_SOT223; SOT-223-3_TabPin2

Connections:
+2.5V: C29.1, U3.2 (VO); also elsewhere on the board
+3.3V: C27.1, R28.2, U2.2 (VO); also elsewhere on the board
+5VA: C25.1, U1.2 (VO); also elsewhere on the board
+12V: C23.1, C24.1, C26.1 (+), C28.1, U1.3 (VI), U2.3 (VI), U3.3 (VI); also elsewhere on the board
/IO/USBVIN: D5.2 (A), Q7.1 (D), R13.1, R14.2; also elsewhere on the board
/voltageregulators/ACDRV: IC5.8 (ACDRV), R17.1
/voltageregulators/ACP: C14.2, C16.1, IC5.5 (ACN), IC5.6 (ACP), R21.1
/voltageregulators/CMSRC: IC5.7 (CMSRC), R20.1
BATTERY_P: C20.2, C21.1, C22.1, D4.2 (A), IC5.15 (SRN), Q9.2 (D), R27.1; also elsewhere on the board
unnamed: C11.1, R13.2
unnamed: D4.1 (K), D5.1 (K), R12.2
unnamed: D6.2 (A), R16.2
unnamed: D6.1 (K), IC5.9 (STAT)
unnamed 111: D7.2 (A), R28.1; also elsewhere on the board
unnamed: IC5.17 (ACSET), R24.1, R25.2
unnamed: C10.1, IC5.4 (AVCC), R12.1
unnamed: C17.1, IC5.21 (BTST)
unnamed: C15.1, IC5.12 (VREF), IC5.14 (CELL), R16.1, R18.2, R22.1, R24.2
unnamed: IC5.13 (ISET), R22.2, R23.1
unnamed: IC5.18 (OVPSET), R14.1, R15.2
unnamed: C18.1, IC5.20 (REGN)
unnamed: C19.2, C20.1, IC5.16 (SRP), IC5.19 (~BATDRV), L1.2, R26.2, R27.2
unnamed: C17.2, IC5.1 (SW_1), IC5.24 (SW_2), L1.1
unnamed: IC5.10 (TS), R18.1, R19.2
unnamed: C13.1, IC5.11 (TTC)
unnamed: Q7.2 (G), Q8.2 (G), R17.2
unnamed: C14.1, Q7.3 (S), Q8.3 (S), R20.2, R21.2
unnamed: Q9.1 (G), R26.1

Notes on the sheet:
Analog references
1.0
3.3V Power indicator
2024-12-14
2.5V LDO
Voltage Regulation
LiPo Battery Charger
5V LDO
voltage regulators
3.3V LDO

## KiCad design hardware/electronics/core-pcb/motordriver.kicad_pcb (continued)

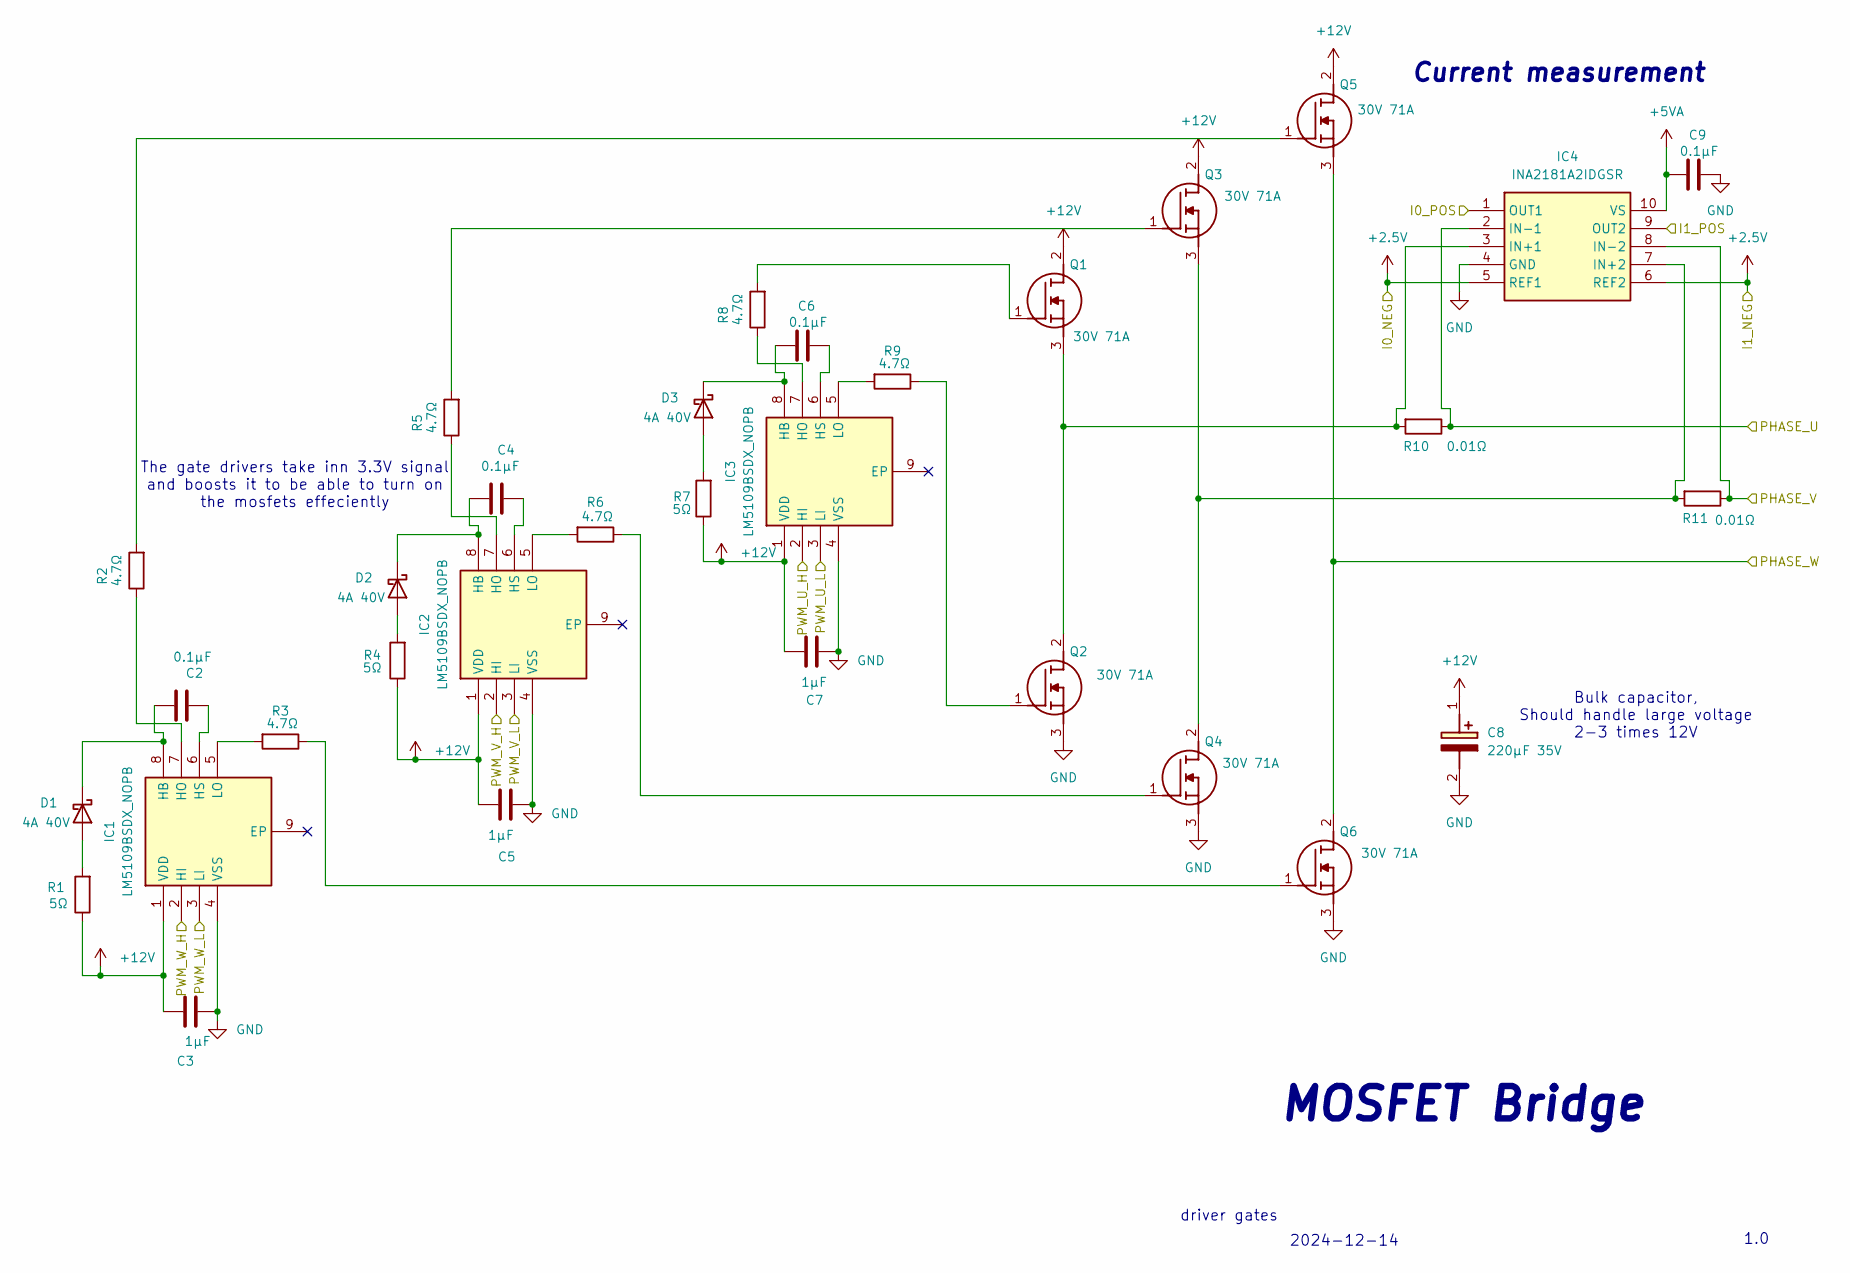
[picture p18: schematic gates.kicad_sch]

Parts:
C2, C4, C6, C9: 0.1µF; C_0603_1608Metric
C3, C5, C7: 1µF; C_0603_1608Metric
C8: 220µF 35V; CAPAE1050X1050N; Mouser Part Number 594-MAL215099001E3
D1, D2, D3: 4A 40V; DIOM7959X262N; Mouser Part Number 78-SL44HE3_B/I
IC1, IC2, IC3: LM5109BSDX_NOPB; SON80P400X400X80-9N; Mouser Part Number 926-LM5109BSDX/NOPB
IC4: INA2181A2IDGSR; SOP50P490X110-10N; Manufacturer_Part_Number INA2181A2IDGSR; Mouser Part Number 595-INA2181A2IDGSR
Q1, Q2, Q3, Q4, Q5, Q6: 30V 71A; IPD047N03LF2SATMA1; Manufacturer_Part_Number IPD047N03LF2SATMA1
R1, R4, R7: 5Ω; R_0603_1608Metric
R2, R3, R5, R6, R8, R9: 4.7Ω; R_0603_1608Metric
R10, R11: 0.01Ω; R_0603_1608Metric

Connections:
+2.5V: IC4.5 (REF1), IC4.6 (REF2); also elsewhere on the board
+5VA: C9.2, IC4.10 (VS); also elsewhere on the board
+12V: C3.1, C5.1, C7.1, C8.1 (+), IC1.1 (VDD), IC2.1 (VDD), IC3.1 (VDD), Q1.2 (D), Q3.2 (D), Q5.2 (D), R1.1, R4.1, R7.1; also elsewhere on the board
/gates1/PHASE_U: IC4.2 (IN-1), R10.1; also elsewhere on the board
/gates1/PHASE_V: IC4.8 (IN-2), R11.1; also elsewhere on the board
/gates1/PHASE_W: Q5.3 (S), Q6.2 (D); also elsewhere on the board
/gates1/PWM_U_H: IC3.2 (HI); also elsewhere on the board
/gates1/PWM_U_L: IC3.3 (LI); also elsewhere on the board
/gates1/PWM_V_H: IC2.2 (HI); also elsewhere on the board
/gates1/PWM_V_L: IC2.3 (LI); also elsewhere on the board
/gates1/PWM_W_H: IC1.2 (HI); also elsewhere on the board
/gates1/PWM_W_L: IC1.3 (LI); also elsewhere on the board
/servo1/ADC_I0_POS: IC4.1 (OUT1); also elsewhere on the board
/servo1/ADC_I1_POS: IC4.9 (OUT2); also elsewhere on the board
unnamed: D1.2 (A), R1.2
unnamed: C2.2, D1.1 (K), IC1.8 (HB)
unnamed: D2.2 (A), R4.2
unnamed: C4.2, D2.1 (K), IC2.8 (HB)
unnamed: D3.2 (A), R7.2
unnamed: C6.2, D3.1 (K), IC3.8 (HB)
unnamed: IC1.7 (HO), R2.1
unnamed: C2.1, IC1.6 (HS)
unnamed: IC1.5 (LO), R3.2
unnamed: IC2.7 (HO), R5.1
unnamed: C4.1, IC2.6 (HS)
unnamed: IC2.5 (LO), R6.2
unnamed: IC3.7 (HO), R8.1
unnamed: C6.1, IC3.6 (HS)
unnamed: IC3.5 (LO), R9.2
unnamed: IC4.3 (IN+1), Q1.3 (S), Q2.2 (D), R10.2
unnamed: IC4.7 (IN+2), Q3.3 (S), Q4.2 (D), R11.2
unnamed: Q1.1 (G), R8.2
unnamed: Q2.1 (G), R9.1
unnamed: Q3.1 (G), R5.2
unnamed: Q4.1 (G), R6.1
unnamed: Q5.1 (G), R2.2
unnamed: Q6.1 (G), R3.1

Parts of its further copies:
C102, C104, C106, C109, C139, C141, C143, C146: 0.1µF; C_0603_1608Metric
C103, C105, C107, C140, C142, C144: 1µF; C_0603_1608Metric
C108, C145: 220µF 35V; CAPAE1050X1050N; Mouser Part Number 594-MAL215099001E3
D51, D52, D53, D73, D74, D75: 4A 40V; DIOM7959X262N; Mouser Part Number 78-SL44HE3_B/I
IC7, IC8, IC9, IC12, IC13, IC14: LM5109BSDX_NOPB; SON80P400X400X80-9N; Mouser Part Number 926-LM5109BSDX/NOPB
IC10, IC15: INA2181A2IDGSR; SOP50P490X110-10N; Manufacturer_Part_Number INA2181A2IDGSR; Mouser Part Number 595-INA2181A2IDGSR
Q10, Q11, Q12, Q13, Q14, Q15, Q17, Q18, Q19, Q20, Q21, Q22: 30V 71A; IPD047N03LF2SATMA1; Manufacturer_Part_Number IPD047N03LF2SATMA1
R64, R67, R70, R89, R92, R95: 5Ω; R_0603_1608Metric
R65, R66, R68, R69, R71, R72, R90, R91, R93, R94, R96, R97: 4.7Ω; R_0603_1608Metric
R73, R74, R98, R99: 0.01Ω; R_0603_1608Metric

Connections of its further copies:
+2.5V: IC10.5 (REF1), IC10.6 (REF2), IC15.5 (REF1), IC15.6 (REF2); also elsewhere on the board
+5VA: C109.2, C146.2, IC10.10 (VS), IC15.10 (VS); also elsewhere on the board
+12V: C103.1, C105.1, C107.1, C108.1 (+), C140.1, C142.1, C144.1, C145.1 (+), IC7.1 (VDD), IC8.1 (VDD), IC9.1 (VDD), IC12.1 (VDD), IC13.1 (VDD), IC14.1 (VDD), Q10.2 (D), Q12.2 (D), Q14.2 (D), Q17.2 (D), Q19.2 (D), Q21.2 (D), R64.1, R67.1, R70.1, R89.1, R92.1, R95.1; also elsewhere on the board
/gates2/PHASE_U: IC10.2 (IN-1), R73.1; also elsewhere on the board
/gates2/PHASE_V: IC10.8 (IN-2), R74.1; also elsewhere on the board
/gates2/PHASE_W: Q14.3 (S), Q15.2 (D); also elsewhere on the board
/gates2/PWM_U_H: IC9.2 (HI); also elsewhere on the board
/gates2/PWM_U_L: IC9.3 (LI); also elsewhere on the board
/gates2/PWM_V_H: IC8.2 (HI); also elsewhere on the board
/gates2/PWM_V_L: IC8.3 (LI); also elsewhere on the board
/gates2/PWM_W_H: IC7.2 (HI); also elsewhere on the board
/gates2/PWM_W_L: IC7.3 (LI); also elsewhere on the board
/gates3/PHASE_U: IC15.2 (IN-1), R98.1; also elsewhere on the board
/gates3/PHASE_V: IC15.8 (IN-2), R99.1; also elsewhere on the board
/gates3/PHASE_W: Q21.3 (S), Q22.2 (D); also elsewhere on the board
/gates3/PWM_U_H: IC14.2 (HI); also elsewhere on the board
/gates3/PWM_U_L: IC14.3 (LI); also elsewhere on the board
/gates3/PWM_V_H: IC13.2 (HI); also elsewhere on the board
/gates3/PWM_V_L: IC13.3 (LI); also elsewhere on the board
/gates3/PWM_W_H: IC12.2 (HI); also elsewhere on the board
/gates3/PWM_W_L: IC12.3 (LI); also elsewhere on the board
/servo2/ADC_I0_POS: IC10.1 (OUT1); also elsewhere on the board
/servo2/ADC_I1_POS: IC10.9 (OUT2); also elsewhere on the board
/servo3/ADC_I0_POS: IC15.1 (OUT1); also elsewhere on the board
/servo3/ADC_I1_POS: IC15.9 (OUT2); also elsewhere on the board
unnamed: D51.2 (A), R64.2
unnamed: C102.2, D51.1 (K), IC7.8 (HB)
unnamed: D52.2 (A), R67.2
unnamed: C104.2, D52.1 (K), IC8.8 (HB)
unnamed: D53.2 (A), R70.2
unnamed: C106.2, D53.1 (K), IC9.8 (HB)
unnamed: D73.2 (A), R89.2
unnamed: C139.2, D73.1 (K), IC12.8 (HB)
unnamed: D74.2 (A), R92.2
unnamed: C141.2, D74.1 (K), IC13.8 (HB)
unnamed: D75.2 (A), R95.2
unnamed: C143.2, D75.1 (K), IC14.8 (HB)
unnamed: IC7.7 (HO), R65.1
unnamed: C102.1, IC7.6 (HS)
unnamed: IC7.5 (LO), R66.2
unnamed: IC8.7 (HO), R68.1
unnamed: C104.1, IC8.6 (HS)
unnamed: IC8.5 (LO), R69.2
unnamed: IC9.7 (HO), R71.1
unnamed: C106.1, IC9.6 (HS)
unnamed: IC9.5 (LO), R72.2
unnamed 173: IC10.3 (IN+1), Q10.3 (S), Q11.2 (D), R73.2; also elsewhere on the board
unnamed 174: IC10.7 (IN+2), Q12.3 (S), Q13.2 (D), R74.2; also elsewhere on the board
unnamed: IC12.7 (HO), R90.1
unnamed: C139.1, IC12.6 (HS)
unnamed: IC12.5 (LO), R91.2
unnamed: IC13.7 (HO), R93.1
unnamed: C141.1, IC13.6 (HS)
unnamed: IC13.5 (LO), R94.2
unnamed: IC14.7 (HO), R96.1
unnamed: C143.1, IC14.6 (HS)
unnamed: IC14.5 (LO), R97.2
unnamed: IC15.3 (IN+1), Q17.3 (S), Q18.2 (D), R98.2
unnamed: IC15.7 (IN+2), Q19.3 (S), Q20.2 (D), R99.2
unnamed 198: Q10.1 (G), R71.2; also elsewhere on the board
unnamed 199: Q11.1 (G), R72.1; also elsewhere on the board
unnamed 200: Q12.1 (G), R68.2; also elsewhere on the board
unnamed 201: Q13.1 (G), R69.1; also elsewhere on the board
unnamed: Q14.1 (G), R65.2
unnamed: Q15.1 (G), R66.1
unnamed: Q17.1 (G), R96.2
unnamed: Q18.1 (G), R97.1
unnamed: Q19.1 (G), R93.2
unnamed: Q20.1 (G), R94.1
unnamed: Q21.1 (G), R90.2
unnamed: Q22.1 (G), R91.1

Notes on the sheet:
1.0
The gate drivers take inn 3.3V signal and boosts it to be able to turn on the mosfets effeciently
MOSFET Bridge
driver gates
2024-12-14
Current measurement
Bulk capacitor, Should handle large voltage 2-3 times 12V

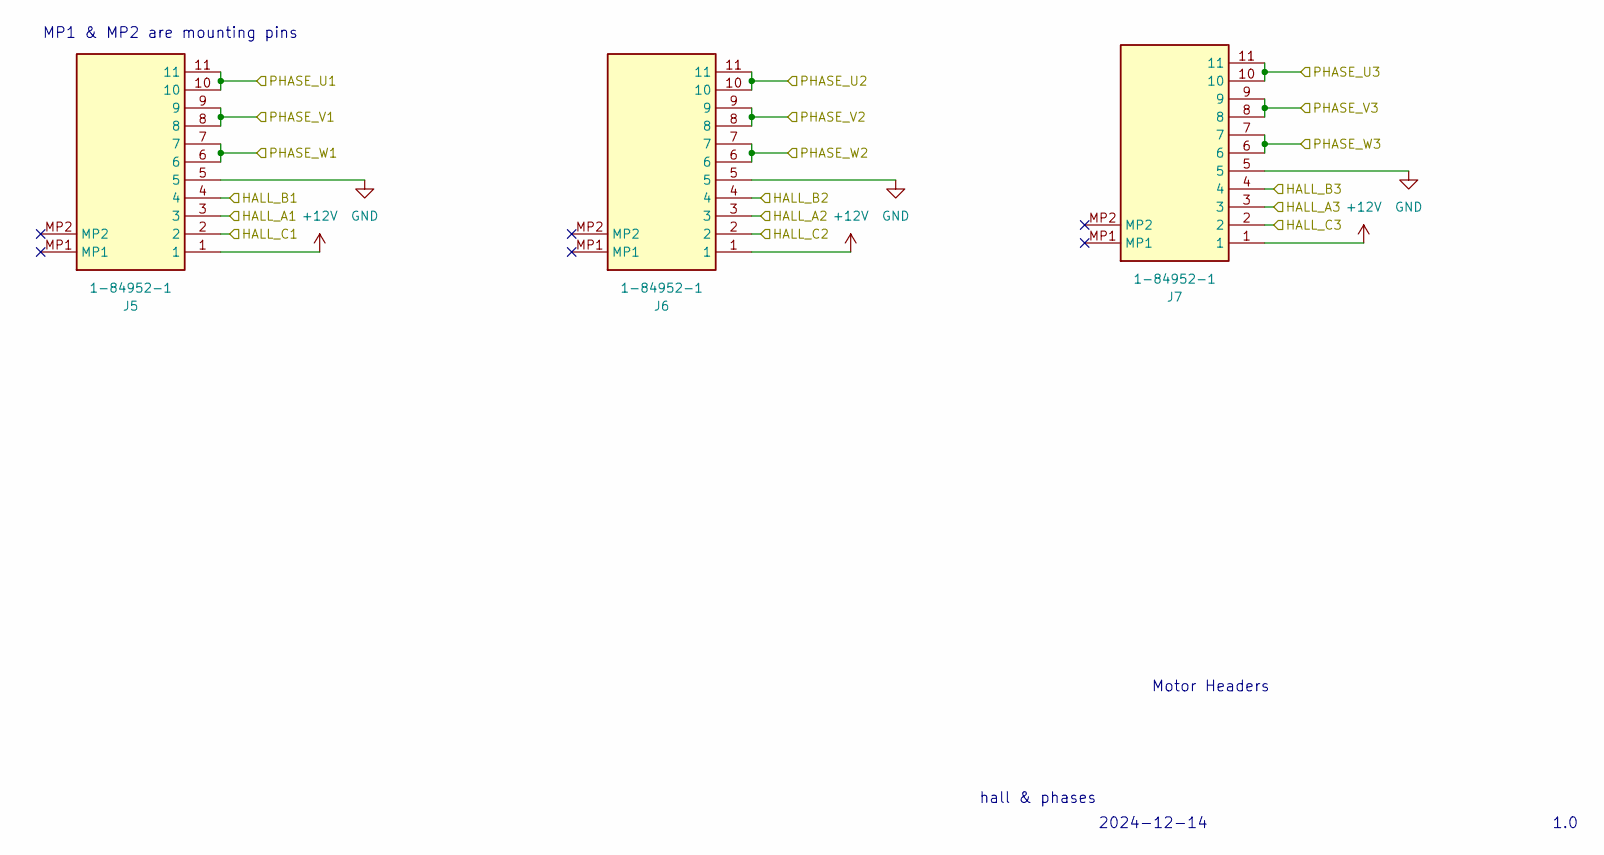
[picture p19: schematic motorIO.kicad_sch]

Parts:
J5, J6, J7: 1-84952-1; 1849521; Mouser Part Number 571-1-84952-1

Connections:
+12V: J5.1, J6.1, J7.1; also elsewhere on the board
/gates1/PHASE_U: J7.10, J7.11; also elsewhere on the board
/gates1/PHASE_V: J7.8, J7.9; also elsewhere on the board
/gates1/PHASE_W: J7.6, J7.7; also elsewhere on the board
/gates2/PHASE_U: J6.10, J6.11; also elsewhere on the board
/gates2/PHASE_V: J6.8, J6.9; also elsewhere on the board
/gates2/PHASE_W: J6.6, J6.7; also elsewhere on the board
/gates3/PHASE_U: J5.10, J5.11; also elsewhere on the board
/gates3/PHASE_V: J5.8, J5.9; also elsewhere on the board
/gates3/PHASE_W: J5.6, J5.7; also elsewhere on the board
/motorIO/HALL_A1: J5.3; also elsewhere on the board
/motorIO/HALL_A2: J6.3; also elsewhere on the board
/motorIO/HALL_A3: J7.3; also elsewhere on the board
/motorIO/HALL_B1: J5.4; also elsewhere on the board
/motorIO/HALL_B2: J6.4; also elsewhere on the board
/motorIO/HALL_B3: J7.4; also elsewhere on the board
/motorIO/HALL_C1: J5.2; also elsewhere on the board
/motorIO/HALL_C2: J6.2; also elsewhere on the board
/motorIO/HALL_C3: J7.2; also elsewhere on the board

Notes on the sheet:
1.0
MP1 & MP2 are mounting pins
Motor Headers
2024-12-14
hall & phases

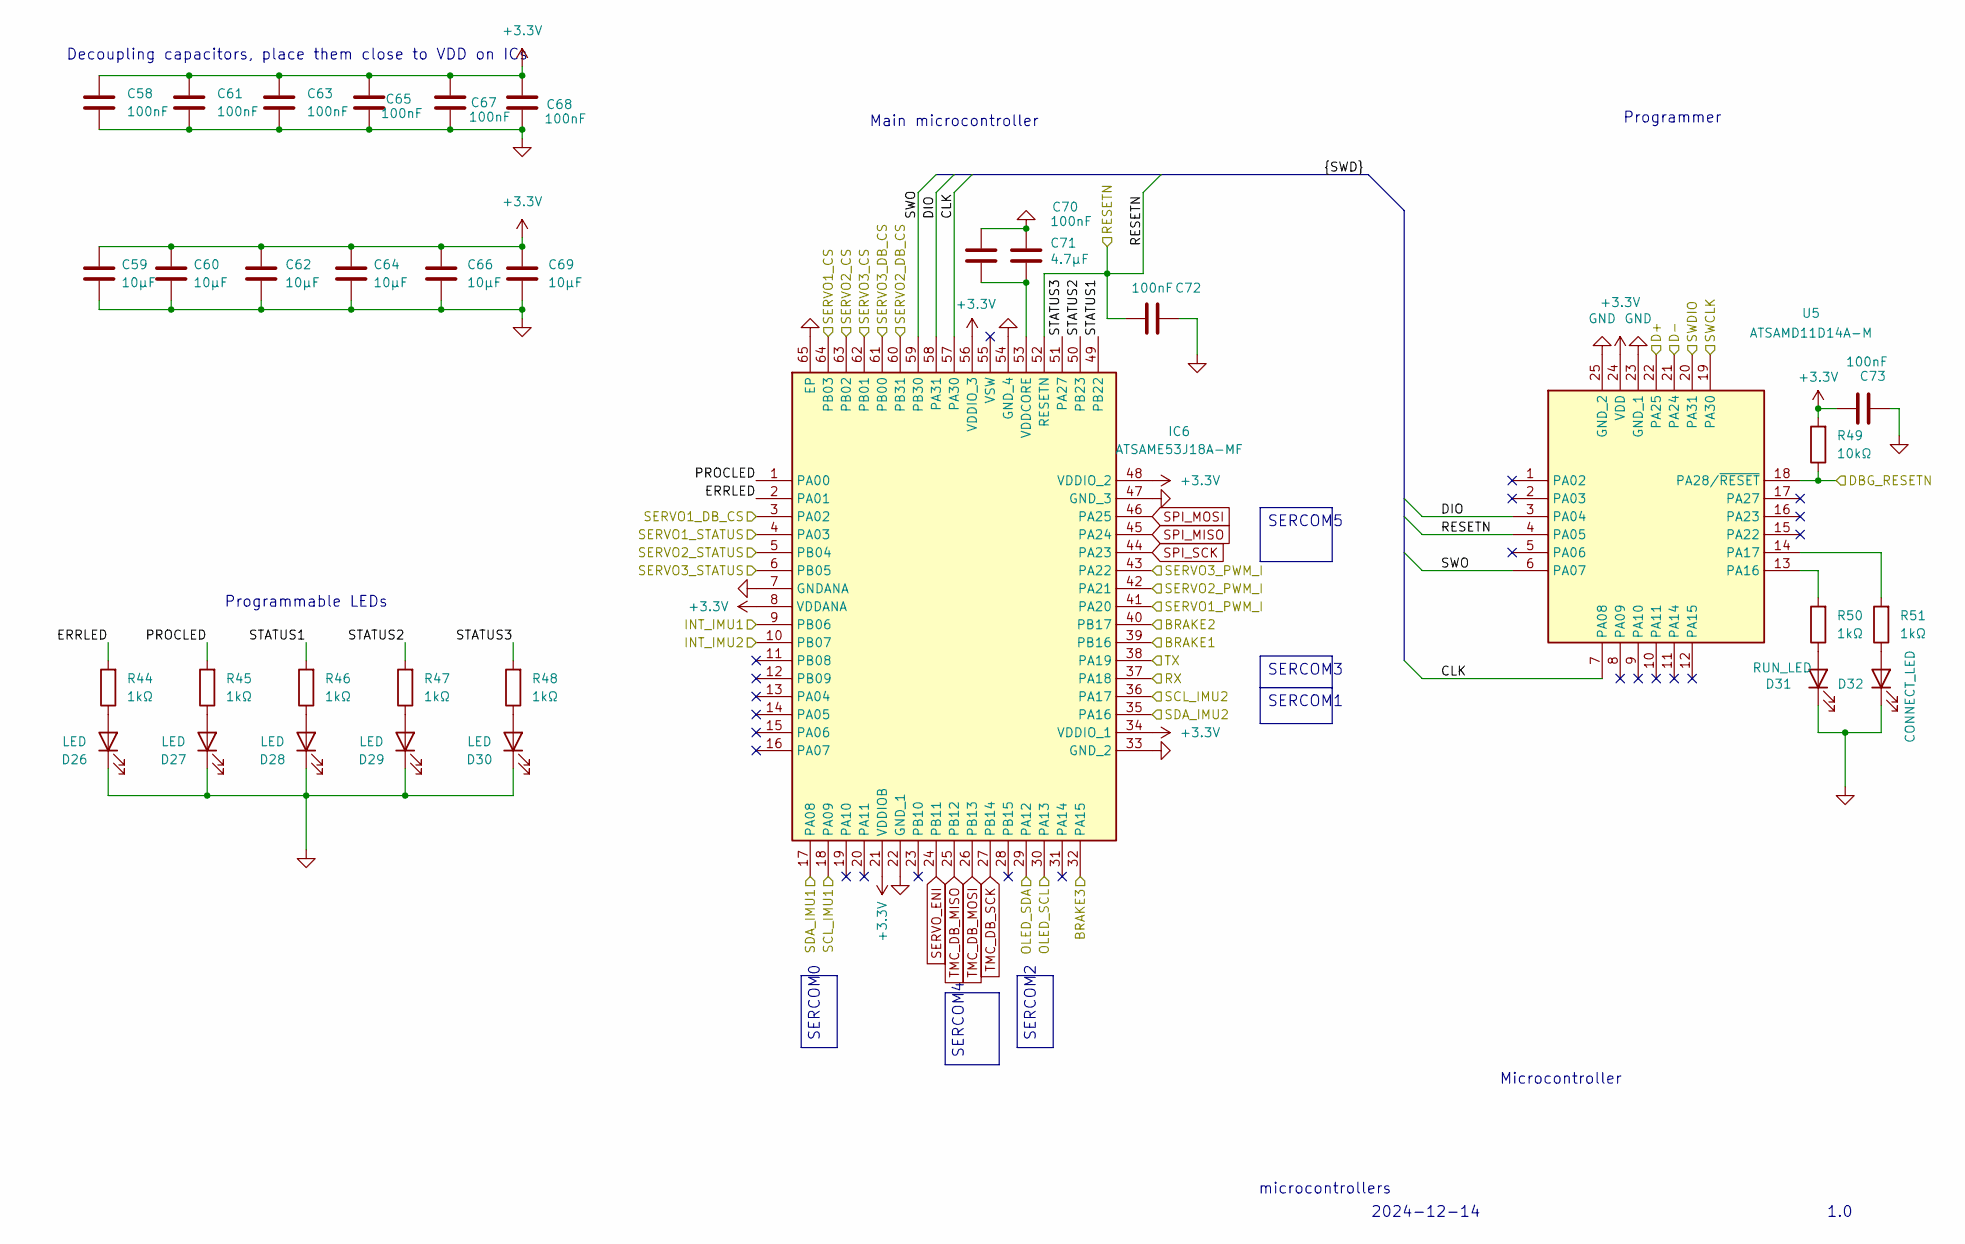
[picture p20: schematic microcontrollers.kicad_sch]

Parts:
C58, C61, C63, C65, C67, C68, C70, C72, C73: 100nF; C_0603_1608Metric
C59, C60, C62, C64, C66, C69: 10µF; C_0603_1608Metric
C71: 4.7µF; C_0603_1608Metric
D26, D27, D28, D29, D30: LED; D_0603_1608Metric
D31: RUN_LED; D_0603_1608Metric
D32: CONNECT_LED; D_0603_1608Metric
IC6: ATSAME53J18A-MF; QFN50P900X900X100-65N-D; Manufacturer_Part_Number ATSAME53J18A-MF; Mouser Part Number 556-ATSAME53J18A-MF
R44, R45, R46, R47, R48, R50, R51: 1kΩ; R_0603_1608Metric
R49: 10kΩ; R_0603_1608Metric
U5: ATSAMD11D14A-M; QFN50P400X400X90-25N-D; Mouser Part Number 556-ATSAMD11D14A-MNT

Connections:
+3.3V: C58.1, C59.1, C60.1, C61.1, C62.1, C63.1, C64.1, C65.1, C66.1, C67.1, C68.1, C69.1, C73.1, IC6.8 (VDDANA), IC6.21 (VDDIOB), IC6.34 (VDDIO_1), IC6.48 (VDDIO_2), IC6.56 (VDDIO_3), R49.2, U5.24 (VDD); also elsewhere on the board
/IO/BRAKE1: IC6.39 (PB16); also elsewhere on the board
/IO/BRAKE2: IC6.40 (PB17); also elsewhere on the board
/IO/BRAKE3: IC6.32 (PA15); also elsewhere on the board
/IO/D+: U5.22 (PA25); also elsewhere on the board
/IO/D-: U5.21 (PA24); also elsewhere on the board
/IO/DBG_RESETN: R49.1, U5.18 (PA28/~RESET); also elsewhere on the board
/IO/DBG_SWCLK: U5.19 (PA30); also elsewhere on the board
/IO/DBG_SWDIO: U5.20 (PA31); also elsewhere on the board
/IO/INT_IMU1: IC6.9 (PB06); also elsewhere on the board
/IO/INT_IMU2: IC6.10 (PB07); also elsewhere on the board
/IO/OLED_SCL: IC6.30 (PA13); also elsewhere on the board
/IO/OLED_SDA: IC6.29 (PA12); also elsewhere on the board
/IO/RX: IC6.37 (PA18); also elsewhere on the board
/IO/SCL_IMU1: IC6.18 (PA09); also elsewhere on the board
/IO/SCL_IMU2: IC6.36 (PA17); also elsewhere on the board
/IO/SDA_IMU1: IC6.17 (PA08); also elsewhere on the board
/IO/SDA_IMU2: IC6.35 (PA16); also elsewhere on the board
/IO/TX: IC6.38 (PA19); also elsewhere on the board
/microcontrollers/CLK: IC6.57 (PA30), U5.7 (PA08)
/microcontrollers/DIO: IC6.58 (PA31), U5.3 (PA04)
/microcontrollers/ERRLED: IC6.2 (PA01), R44.2; also elsewhere on the board
/microcontrollers/PROCLED: IC6.1 (PA00), R45.2; also elsewhere on the board
/microcontrollers/RESETN: C72.1, IC6.52 (RESETN), U5.4 (PA05); also elsewhere on the board
/microcontrollers/SERVO1_CS: IC6.64 (PB03); also elsewhere on the board
/microcontrollers/SERVO1_DB_CS: IC6.3 (PA02); also elsewhere on the board
/microcontrollers/SERVO1_PWM_I: IC6.41 (PA20); also elsewhere on the board
/microcontrollers/SERVO1_STATUS: IC6.4 (PA03); also elsewhere on the board
/microcontrollers/SERVO2_CS: IC6.63 (PB02); also elsewhere on the board
/microcontrollers/SERVO2_DB_CS: IC6.60 (PB31); also elsewhere on the board
/microcontrollers/SERVO2_PWM_I: IC6.42 (PA21); also elsewhere on the board
/microcontrollers/SERVO2_STATUS: IC6.5 (PB04); also elsewhere on the board
/microcontrollers/SERVO3_CS: IC6.62 (PB01); also elsewhere on the board
/microcontrollers/SERVO3_DB_CS: IC6.61 (PB00); also elsewhere on the board
/microcontrollers/SERVO3_PWM_I: IC6.43 (PA22); also elsewhere on the board
/microcontrollers/SERVO3_STATUS: IC6.6 (PB05); also elsewhere on the board
/microcontrollers/STATUS1: IC6.49 (PB22), R46.2
/microcontrollers/STATUS2: IC6.50 (PB23), R47.2
/microcontrollers/STATUS3: IC6.51 (PA27), R48.2
/microcontrollers/SWO: IC6.59 (PB30), U5.6 (PA07)
unnamed: D26.2 (A), R44.1
unnamed: D27.2 (A), R45.1
unnamed: D28.2 (A), R46.1
unnamed: D29.2 (A), R47.1
unnamed: D30.2 (A), R48.1
unnamed: D31.2 (A), R50.1
unnamed: D32.2 (A), R51.1
unnamed: C70.2, C71.2, IC6.53 (VDDCORE)
unnamed: R50.2, U5.13 (PA16)
unnamed: R51.2, U5.14 (PA17)
SERVO_ENI: IC6.24 (PB11); also elsewhere on the board
SPI_MISO: IC6.45 (PA24); also elsewhere on the board
SPI_MOSI: IC6.46 (PA25); also elsewhere on the board
SPI_SCK: IC6.44 (PA23); also elsewhere on the board
TMC_DB_MISO: IC6.25 (PB12); also elsewhere on the board
TMC_DB_MOSI: IC6.26 (PB13); also elsewhere on the board
TMC_DB_SCK: IC6.27 (PB14); also elsewhere on the board

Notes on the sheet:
Main microcontroller
1.0
microcontrollers
Programmable LEDs
Microcontroller
2024-12-14
Programmer
Decoupling capacitors, place them close to VDD on ICs
SERCOM0
SERCOM4
SERCOM5
SERCOM1
SERCOM2
SERCOM3

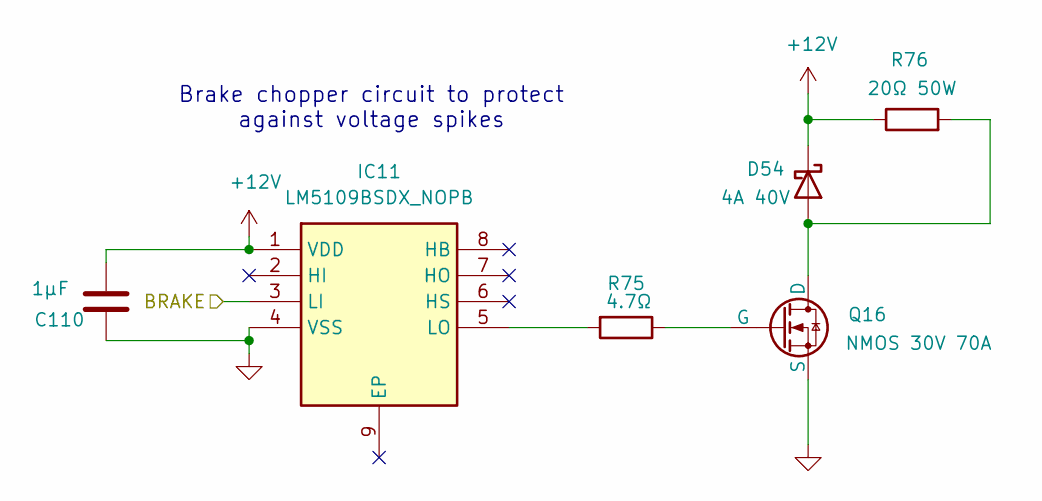
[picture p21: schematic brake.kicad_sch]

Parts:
C110: 1µF; C_0603_1608Metric
D54: 4A 40V; DIOM7959X262N; Mouser Part Number 78-SL44HE3_B/I
IC11: LM5109BSDX_NOPB; SON80P400X400X80-9N; Mouser Part Number 926-LM5109BSDX/NOPB
Q16: NMOS 30V 70A; IPD047N03LF2SATMA1
R75: 4.7Ω; R_0603_1608Metric
R76: 20Ω 50W

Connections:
+12V: C110.1, D54.1 (K), IC11.1 (VDD), R76.1; also elsewhere on the board
/brake/BRAKE: IC11.3 (LI); also elsewhere on the board
unnamed: D54.2 (A), Q16.1 (D), R76.2
unnamed: IC11.5 (LO), R75.2
unnamed: Q16.2 (G), R75.1

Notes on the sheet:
Brake chopper circuit to protect against voltage spikes

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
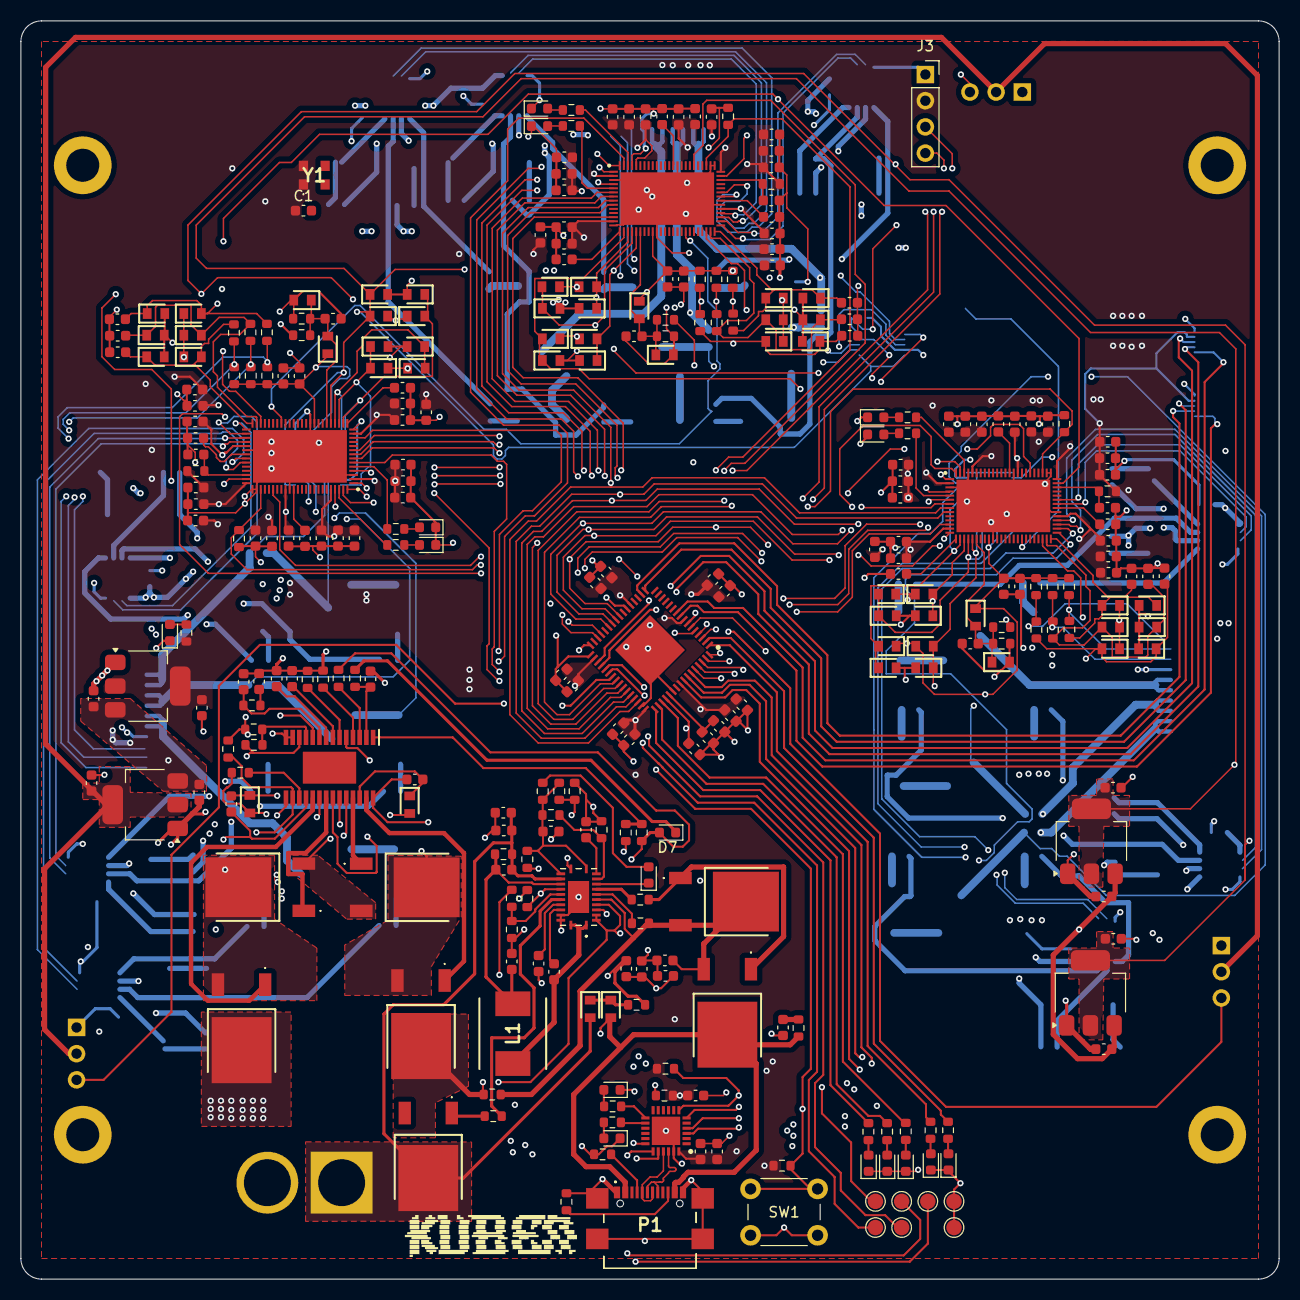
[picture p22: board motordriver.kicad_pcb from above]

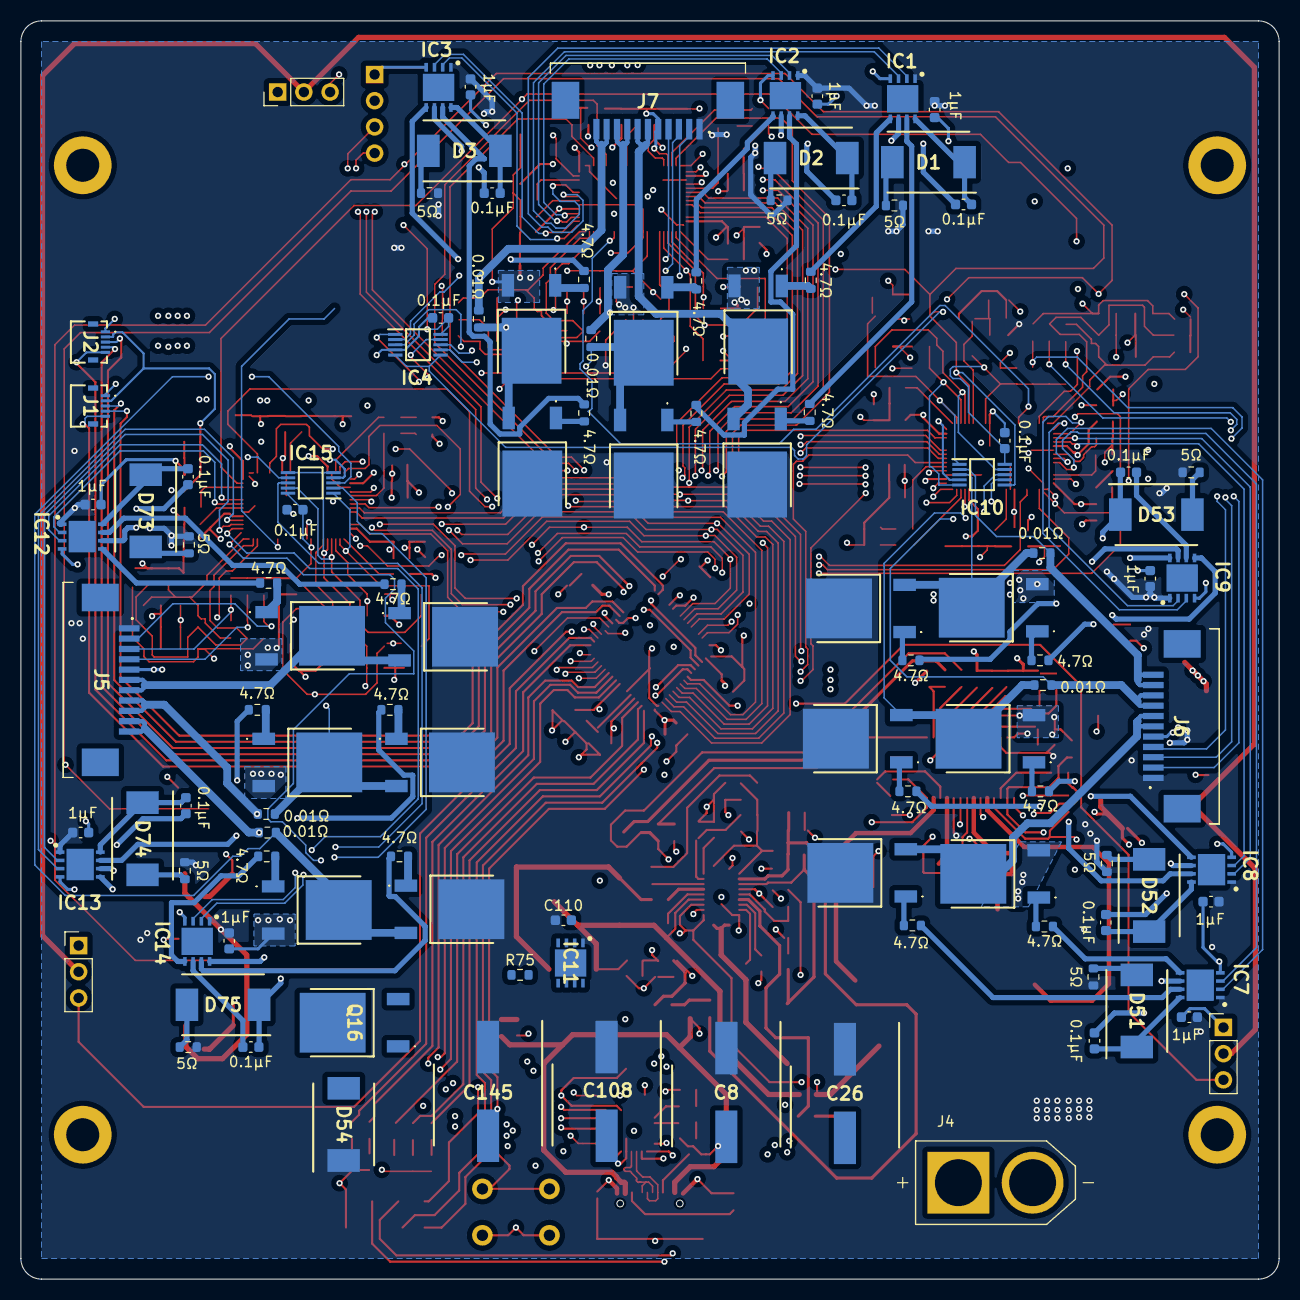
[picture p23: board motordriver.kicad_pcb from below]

Board: 4 copper layers, 122.0 x 122.0 mm, 418 parts (111 on the bottom side), 241 nets.

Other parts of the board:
C22#2: 10µF; C_0603_1608Metric
C26#2: 220µF 35V; CAPAE1050X1050N
C30#2, C32#2, C33#2, C35#2, C36#2: 100nF; C_0603_1608Metric
C34#2, C37#2: 100pF; C_0603_1608Metric
D7#2: PWR; D_0603_1608Metric
D9#2, D10#2: 4.7Vf 0.5A; DIOC1709X85N
IC6#2: ATSAME53J18A-MF; SOP65P640X120-29N
Q10#2, Q11#2, Q12#2, Q13#2: 30V 71A; IPD047N03LF2SATMA1
R28#2, R35#2, R36#2, R37#2, R39#2: 1kΩ; R_0603_1608Metric
R30#2: 5.1kΩ; R_0603_1608Metric
R31#2, R38#2, R60#2: 10kΩ; R_0603_1608Metric
R32#2, R33#2, R34#2: 4.7kΩ; R_0603_1608Metric
U3#2: LD1117S25TR_SOT223; SOT-223-3_TabPin2

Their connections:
+2.5V: U3#2.2 (VO); also elsewhere on the board
+3.3V: C30#2.2, C32#2.2, C33#2.2, C35#2.2, IC6#2.8 (VDDANA), IC6#2.21 (VDDIOB), R28#2.2, R31#2.1, R60#2.2; also elsewhere on the board
+5VA: D10#2.1 (K), R32#2.1, R33#2.1, R34#2.1; also elsewhere on the board
+12V: C26#2.1 (+), Q10#2.2 (D), Q12#2.2 (D), U3#2.3 (VI); also elsewhere on the board
/IO/INT_IMU1: IC6#2.9 (PB06); also elsewhere on the board
/IO/INT_IMU2: IC6#2.10 (PB07); also elsewhere on the board
/IO/OLED_SDA: IC6#2.29 (PA12); also elsewhere on the board
/IO/SCL_IMU1: IC6#2.18 (PA09); also elsewhere on the board
/IO/SDA_IMU1: IC6#2.17 (PA08); also elsewhere on the board
/microcontrollers/ERRLED: IC6#2.2 (PA01); also elsewhere on the board
/microcontrollers/PROCLED: IC6#2.1 (PA00); also elsewhere on the board
/microcontrollers/RESETN: R31#2.2; also elsewhere on the board
/microcontrollers/SERVO1_DB_CS: IC6#2.3 (PA02); also elsewhere on the board
/microcontrollers/SERVO1_STATUS: IC6#2.4 (PA03); also elsewhere on the board
/microcontrollers/SERVO2_STATUS: IC6#2.5 (PB04); also elsewhere on the board
/microcontrollers/SERVO3_STATUS: IC6#2.6 (PB05); also elsewhere on the board
/motorIO/HALL_A3: R32#2.2, R37#2.1; also elsewhere on the board
/motorIO/HALL_B3: R33#2.2, R36#2.1; also elsewhere on the board
/motorIO/HALL_C3: R34#2.2, R35#2.1; also elsewhere on the board
/servo1/ADC_I0_POS: D9#2.1 (K); also elsewhere on the board
/servo1/ADC_I1_POS: D10#2.2 (A); also elsewhere on the board
/servo1/HALL_U_FILT: C34#2.2, R37#2.2; also elsewhere on the board
/servo1/HALL_V_FILT: C37#2.2, R36#2.2; also elsewhere on the board
/servo1/HALL_W_FILT: R35#2.2; also elsewhere on the board
BATTERY_P: C22#2.1; also elsewhere on the board
unnamed 111: D7#2.2 (A), R28#2.1; also elsewhere on the board
unnamed 112: R39#2.1; also elsewhere on the board
unnamed 173: Q10#2.3 (S), Q11#2.2 (D); also elsewhere on the board
unnamed 174: Q12#2.3 (S), Q13#2.2 (D); also elsewhere on the board
unnamed 188: R30#2.2; also elsewhere on the board
unnamed 198: Q10#2.1 (G); also elsewhere on the board
unnamed 199: Q11#2.1 (G); also elsewhere on the board
unnamed 200: Q12#2.1 (G); also elsewhere on the board
unnamed 201: Q13#2.1 (G); also elsewhere on the board
unnamed 211: R39#2.2; also elsewhere on the board
unnamed 216: C36#2.2; also elsewhere on the board
unnamed 221: R60#2.1; also elsewhere on the board
SERVO_ENI: IC6#2.24 (PB11), R38#2.1; also elsewhere on the board
TMC_DB_MISO: IC6#2.25 (PB12); also elsewhere on the board
TMC_DB_MOSI: IC6#2.26 (PB13); also elsewhere on the board
TMC_DB_SCK: IC6#2.27 (PB14); also elsewhere on the board

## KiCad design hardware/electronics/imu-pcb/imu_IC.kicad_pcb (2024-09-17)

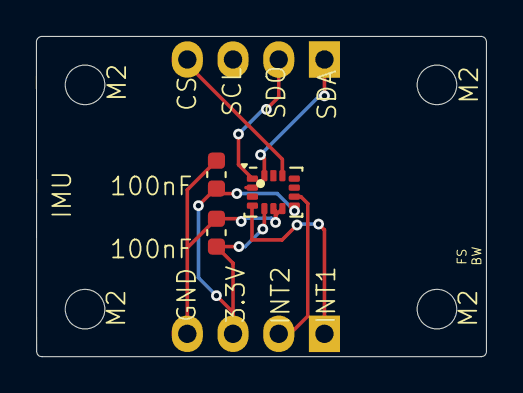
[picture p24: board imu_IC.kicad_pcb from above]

Board: 2 copper layers, 25.0 x 17.8 mm, 9 parts (0 on the bottom side), 7 nets.

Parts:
C1, C2: C; C_0603_1608Metric
H1, H2, H3, H4: MountingHole_Pad; MountingHole_2.2mm_M2
J1, J2: Conn_01x04; FanPinHeader_1x04_P2.54mm_Vertical
U1: ISM330DHCX; LGA-14_3x2.5mm_P0.5mm_LayoutBorder3x4y

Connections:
+3.3V: C1.1, C2.1, J2.3, U1.5 (VDDIO), U1.8 (VDD)
CS: J1.4, U1.12 (CS)
GND: C1.2, C2.2, J2.4, U1.6 (GND), U1.7 (GND)
INT1: J2.1, U1.4 (INT1)
INT2: J2.2, U1.9 (INT2)
SDA: J1.1, U1.14 (SDA)
SDO/SAO: J1.2, U1.1 (SDO/SA0)

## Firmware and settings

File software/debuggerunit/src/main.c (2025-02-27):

// SPDX-License-Identifier: BSD-3-Clause
// Copyright (c) 2017-2022, Alex Taradov <alex@taradov.com>. All rights reserved.

/*- Includes ----------------------------------------------------------------*/
#include <stdlib.h>
#include <stdint.h>
#include <stdbool.h>
#include <stdalign.h>
#include <string.h>
#include "platform/samd11d14am.h"
#include "platform/hal_config.h"
#include "platform/nvm_data.h"
#include "platform/drivers/usb.h"
#include "platform/drivers/uart.h"
#include "dap.h"
#include "dap_config.h"

/*- Definitions -------------------------------------------------------------*/
#define USB_BUFFER_SIZE        64
#define UART_WAIT_TIMEOUT      10 // ms
#define STATUS_TIMEOUT         250 // ms

/*- Variables ---------------------------------------------------------------*/
static alignas(4) uint8_t app_req_buf_hid[DAP_CONFIG_PACKET_SIZE];
static alignas(4) uint8_t app_req_buf_bulk[DAP_CONFIG_PACKET_SIZE];
static alignas(4) uint8_t app_req_buf[DAP_CONFIG_PACKET_SIZE];
static alignas(4) uint8_t app_resp_buf[DAP_CONFIG_PACKET_SIZE];
static int app_req_buf_hid_size = 0;
static int app_req_buf_bulk_size = 0;
static bool app_resp_free = true;
static uint64_t app_system_time = 0;
static uint64_t app_status_timeout = 0;
static bool app_dap_event = false;

#ifdef HAL_CONFIG_ENABLE_VCP
static alignas(4) uint8_t app_recv_buffer[USB_BUFFER_SIZE];
static alignas(4) uint8_t app_send_buffer[USB_BUFFER_SIZE];
static int app_recv_buffer_size = 0;
static int app_recv_buffer_ptr = 0;
static int app_send_buffer_ptr = 0;
static bool app_send_buffer_free = true;
static bool app_send_zlp = false;
static uint64_t app_uart_timeout = 0;
static uint64_t app_break_timeout = 0;
static bool app_vcp_event = false;
static bool app_vcp_open = false;
#endif

/*- Implementations ---------------------------------------------------------*/

//-----------------------------------------------------------------------------
static void sys_init(void)
{
  uint32_t coarse, fine;

  NVMCTRL->CTRLB.reg = NVMCTRL_CTRLB_RWS(1);

  SYSCTRL->INTFLAG.reg = SYSCTRL_INTFLAG_BOD33RDY | SYSCTRL_INTFLAG_BOD33DET |
      SYSCTRL_INTFLAG_DFLLRDY;

  coarse = NVM_READ_CAL(NVM_DFLL48M_COARSE_CAL);
  fine = NVM_READ_CAL(NVM_DFLL48M_FINE_CAL);

  SYSCTRL->DFLLCTRL.reg = 0; // See Errata 9905
  while (0 == (SYSCTRL->PCLKSR.reg & SYSCTRL_PCLKSR_DFLLRDY));

  SYSCTRL->DFLLMUL.reg = SYSCTRL_DFLLMUL_MUL(48000);
  SYSCTRL->DFLLVAL.reg = SYSCTRL_DFLLVAL_COARSE(coarse) | SYSCTRL_DFLLVAL_FINE(fine);

  SYSCTRL->DFLLCTRL.reg = SYSCTRL_DFLLCTRL_ENABLE | SYSCTRL_DFLLCTRL_USBCRM |
      SYSCTRL_DFLLCTRL_MODE | SYSCTRL_DFLLCTRL_CCDIS;

  while (0 == (SYSCTRL->PCLKSR.reg & SYSCTRL_PCLKSR_DFLLRDY));

  GCLK->GENCTRL.reg = GCLK_GENCTRL_ID(0) | GCLK_GENCTRL_SRC(GCLK_SOURCE_DFLL48M) |
      GCLK_GENCTRL_RUNSTDBY | GCLK_GENCTRL_GENEN;
  while (GCLK->STATUS.reg & GCLK_STATUS_SYNCBUSY);
}

//-----------------------------------------------------------------------------
static void serial_number_init(void)
{
  uint32_t wuid[4];
  uint8_t *uid = (uint8_t *)wuid;
  uint32_t sn = 5381;

  wuid[0] = *(volatile uint32_t *)0x0080a00c;
  wuid[1] = *(volatile uint32_t *)0x0080a040;
  wuid[2] = *(volatile uint32_t *)0x0080a044;
  wuid[3] = *(volatile uint32_t *)0x0080a048;

  for (int i = 0; i < 16; i++)
    sn = ((sn << 5) + sn) ^ uid[i];

  for (int i = 0; i < 8; i++)
    usb_serial_number[i] = "0123456789ABCDEF"[(sn >> (i * 4)) & 0xf];

  usb_serial_number[8] = 0;
}

//-----------------------------------------------------------------------------
static void sys_time_init(void)
{
  SysTick->VAL  = 0;
  SysTick->LOAD = F_CPU / 1000ul;
  SysTick->CTRL = SysTick_CTRL_ENABLE_Msk;
  app_system_time = 0;
}

//-----------------------------------------------------------------------------
static void sys_time_task(void)
{
  if (SysTick->CTRL & SysTick_CTRL_COUNTFLAG_Msk)
    app_system_time++;
}

#ifdef HAL_CONFIG_ENABLE_VCP
//-----------------------------------------------------------------------------
static void tx_task(void)
{
  while (app_recv_buffer_size)
  {
    if (!uart_write_byte(app_recv_buffer[app_recv_buffer_ptr]))
      break;

    app_recv_buffer_ptr++;
    app_recv_buffer_size--;
    app_vcp_event = true;

    if (0 == app_recv_buffer_size)
      usb_cdc_recv(app_recv_buffer, sizeof(app_recv_buffer));
  }
}

//-----------------------------------------------------------------------------
static void send_buffer(void)
{
  app_send_buffer_free = false;
  app_send_zlp = (USB_BUFFER_SIZE == app_send_buffer_ptr);

  usb_cdc_send(app_send_buffer, app_send_buffer_ptr);

  app_send_buffer_ptr = 0;
}

//-----------------------------------------------------------------------------
static void rx_task(void)
{
  int byte;

  if (!app_send_buffer_free)
    return;

  while (uart_read_byte(&byte))
  {
    int state = (byte >> 8) & 0xff;

    app_uart_timeout = app_system_time + UART_WAIT_TIMEOUT;
    app_vcp_event = true;

    if (state)
    {
      usb_cdc_set_state(state);
    }
    else
    {
      app_send_buffer[app_send_buffer_ptr++] = byte;

      if (USB_BUFFER_SIZE == app_send_buffer_ptr)
      {
        send_buffer();
        break;
      }
    }
  }
}

//-----------------------------------------------------------------------------
static void break_task(void)
{
  if (app_break_timeout && app_system_time > app_break_timeout)
  {
    uart_set_break(false);
    app_break_timeout = 0;
  }
}

//-----------------------------------------------------------------------------
static void uart_timer_task(void)
{
  if (app_uart_timeout && app_system_time > app_uart_timeout)
  {
    if (app_send_zlp || app_send_buffer_ptr)
      send_buffer();

    app_uart_timeout = 0;
  }
}

//-----------------------------------------------------------------------------
void usb_cdc_line_coding_updated(usb_cdc_line_coding_t *line_coding)
{
  uart_init(line_coding);
}

//-----------------------------------------------------------------------------
void usb_cdc_control_line_state_update(int line_state)
{
  bool status = line_state & USB_CDC_CTRL_SIGNAL_DTE_PRESENT;

  app_vcp_open        = status;
  app_send_buffer_ptr = 0;
  app_uart_timeout    = 0;
  app_break_timeout   = 0;

  if (app_vcp_open)
    uart_init(usb_cdc_get_line_coding());
  else
    uart_close();
}

//-----------------------------------------------------------------------------
void usb_cdc_send_break(int duration)
{
  if (USB_CDC_BREAK_DURATION_DISABLE == duration)
  {
    app_break_timeout = 0;
    uart_set_break(false);
  }
  else if (USB_CDC_BREAK_DURATION_INFINITE == duration)
  {
    app_break_timeout = 0;
    uart_set_break(true);
  }
  else
  {
    app_break_timeout = app_system_time + duration;
    uart_set_break(true);
  }
}

//-----------------------------------------------------------------------------
void usb_cdc_send_callback(void)
{
  app_send_buffer_free = true;
}

//-----------------------------------------------------------------------------
void usb_cdc_recv_callback(int size)
{
  app_recv_buffer_ptr = 0;
  app_recv_buffer_size = size;
}
#endif // HAL_CONFIG_ENABLE_VCP

//-----------------------------------------------------------------------------
void usb_hid_send_callback(void)
{
  app_resp_free = true;
}

//-----------------------------------------------------------------------------
void usb_hid_recv_callback(int size)
{
  app_req_buf_hid_size = size;
}

//-----------------------------------------------------------------------------
static void usb_bulk_send_callback(void)
{
  app_resp_free = true;
}

//-----------------------------------------------------------------------------
static void usb_bulk_recv_callback(int size)
{
  app_req_buf_bulk_size = size;
}

//-----------------------------------------------------------------------------
static void dap_task(void)
{
  int interface, size;

  if (!app_resp_free)
    return;

  if (app_req_buf_hid_size)
  {
    interface = USB_INTF_HID;
    size = app_req_buf_hid_size;
    app_req_buf_hid_size = 0;

    memcpy(app_req_buf, app_req_buf_hid, size);

    usb_hid_recv(app_req_buf_hid, sizeof(app_req_buf_hid));
  }
  else if (app_req_buf_bulk_size)
  {
    interface = USB_INTF_BULK;
    size = app_req_buf_bulk_size;
    app_req_buf_bulk_size = 0;

    memcpy(app_req_buf, app_req_buf_bulk, size);

    usb_recv(USB_BULK_EP_RECV, app_req_buf_bulk, sizeof(app_req_buf_bulk));
  }
  else
  {
    return;
  }

  size = dap_process_request(app_req_buf, size, app_resp_buf, sizeof(app_resp_buf));

  if (USB_INTF_BULK == interface)
    usb_send(USB_BULK_EP_SEND, app_resp_buf, size);
  else
    usb_hid_send(app_resp_buf, sizeof(app_resp_buf));

  app_resp_free = false;
  app_dap_event = true;
}

//-----------------------------------------------------------------------------
void usb_configuration_callback(int config)
{
  app_resp_free = true;
  app_req_buf_hid_size = 0;
  app_req_buf_bulk_size = 0;

  usb_set_send_callback(USB_BULK_EP_SEND, usb_bulk_send_callback);
  usb_set_recv_callback(USB_BULK_EP_RECV, usb_bulk_recv_callback);

  usb_hid_recv(app_req_buf_hid, sizeof(app_req_buf_hid));
  usb_recv(USB_BULK_EP_RECV, app_req_buf_bulk, sizeof(app_req_buf_bulk));

#ifdef HAL_CONFIG_ENABLE_VCP
  usb_cdc_recv(app_recv_buffer, sizeof(app_recv_buffer));

  app_send_buffer_free = true;
  app_send_buffer_ptr = 0;
#endif

  (void)config;
}

//-----------------------------------------------------------------------------
static void status_timer_task(void)
{
  if (app_system_time < app_status_timeout)
    return;

  app_status_timeout = app_system_time + STATUS_TIMEOUT;

  if (app_dap_event)
    HAL_GPIO_DAP_STATUS_toggle();
  else
    HAL_GPIO_DAP_STATUS_set();

  app_dap_event = false;

#ifdef HAL_CONFIG_ENABLE_VCP
  if (app_vcp_event)
    HAL_GPIO_VCP_STATUS_toggle();
  else
    HAL_GPIO_VCP_STATUS_write(app_vcp_open);

  app_vcp_event = false;
#endif
}

//-----------------------------------------------------------------------------
int main(void)
{
  sys_init();
  sys_time_init();
  dap_init();
  usb_init();
#ifdef HAL_CONFIG_ENABLE_VCP
  usb_cdc_init();
#endif
  usb_hid_init();
  serial_number_init();

  app_status_timeout = STATUS_TIMEOUT;

#ifdef HAL_CONFIG_ENABLE_VCP
  HAL_GPIO_VCP_STATUS_out();
  HAL_GPIO_VCP_STATUS_clr();
#endif

  HAL_GPIO_DAP_STATUS_out();
  HAL_GPIO_DAP_STATUS_set();

  // HAL_GPIO_BOOT_ENTER_in();
  // HAL_GPIO_BOOT_ENTER_pullup();

  while (1)
  {
    sys_time_task();
    status_timer_task();
    usb_task();
    dap_task();

#ifdef HAL_CONFIG_ENABLE_VCP
    tx_task();
    rx_task();
    break_task();
    uart_timer_task();
#endif

  //   if (0 == HAL_GPIO_BOOT_ENTER_read())
  //     NVIC_SystemReset();
  }

  return 0;
}

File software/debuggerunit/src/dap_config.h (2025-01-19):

// SPDX-License-Identifier: BSD-3-Clause
// Copyright (c) 2017-2022, Alex Taradov <alex@taradov.com>. All rights reserved.

#ifndef _DAP_CONFIG_H_
#define _DAP_CONFIG_H_

/*- Includes ----------------------------------------------------------------*/
#include "platform/samd11d14am.h"
#include "platform/hal_config.h"

/*- Definitions -------------------------------------------------------------*/
#define DAP_CONFIG_DEFAULT_PORT        DAP_PORT_SWD
#define DAP_CONFIG_DEFAULT_CLOCK       1000000 // Hz

#define DAP_CONFIG_PACKET_SIZE         64
#define DAP_CONFIG_PACKET_COUNT        2

#define DAP_CONFIG_JTAG_DEV_COUNT      8

// DAP_CONFIG_PRODUCT_STR must contain "CMSIS-DAP" to be compatible with the standard
#define DAP_CONFIG_VENDOR_STR          "Alex Taradov"
#define DAP_CONFIG_PRODUCT_STR         "Generic CMSIS-DAP Adapter"
#define DAP_CONFIG_SER_NUM_STR         usb_serial_number
#define DAP_CONFIG_CMSIS_DAP_VER_STR   "2.0.0"

//#define DAP_CONFIG_RESET_TARGET_FN     target_specific_reset_function
//#define DAP_CONFIG_VENDOR_FN           vendor_command_handler_function

// Attribute to use for performance-critical functions
#define DAP_CONFIG_PERFORMANCE_ATTR    __attribute__((section(".ramfunc")))

// A value at which dap_clock_test() produces 1 kHz output on the SWCLK pin
#define DAP_CONFIG_DELAY_CONSTANT      7700

// A threshold for switching to fast clock (no added delays)
// This is the frequency produced by dap_clock_test(1) on the SWCLK pin
#define DAP_CONFIG_FAST_CLOCK          2400000 // Hz

/*- Prototypes --------------------------------------------------------------*/
extern char usb_serial_number[16];

/*- Implementations ---------------------------------------------------------*/

//-----------------------------------------------------------------------------
static inline void DAP_CONFIG_SWCLK_TCK_write(int value)
{
  HAL_GPIO_SWCLK_TCK_write(value);
}

//-----------------------------------------------------------------------------
static inline void DAP_CONFIG_SWDIO_TMS_write(int value)
{
  HAL_GPIO_SWDIO_TMS_write(value);
}

//-----------------------------------------------------------------------------
static inline void DAP_CONFIG_TDI_write(int value)
{
#ifdef DAP_CONFIG_ENABLE_JTAG
  HAL_GPIO_TDI_write(value);
#else
  (void)value;
#endif
}

//-----------------------------------------------------------------------------
static inline void DAP_CONFIG_TDO_write(int value)
{
#ifdef DAP_CONFIG_ENABLE_JTAG
  HAL_GPIO_TDO_write(value);
#else
  (void)value;
#endif
}

//-----------------------------------------------------------------------------
static inline void DAP_CONFIG_nTRST_write(int value)
{
  (void)value;
}

//-----------------------------------------------------------------------------
static inline void DAP_CONFIG_nRESET_write(int value)
{
  HAL_GPIO_nRESET_write(value);
}

//-----------------------------------------------------------------------------
static inline int DAP_CONFIG_SWCLK_TCK_read(void)
{
  return HAL_GPIO_SWCLK_TCK_read();
}

//-----------------------------------------------------------------------------
static inline int DAP_CONFIG_SWDIO_TMS_read(void)
{
  return HAL_GPIO_SWDIO_TMS_read();
}

//-----------------------------------------------------------------------------
static inline int DAP_CONFIG_TDO_read(void)
{
#ifdef DAP_CONFIG_ENABLE_JTAG
  return HAL_GPIO_TDO_read();
#else
  return 0;
#endif
}

//-----------------------------------------------------------------------------
static inline int DAP_CONFIG_TDI_read(void)
{
#ifdef DAP_CONFIG_ENABLE_JTAG
  return HAL_GPIO_TDI_read();
#else
  return 0;
#endif
}

//-----------------------------------------------------------------------------
static inline int DAP_CONFIG_nTRST_read(void)
{
  return 0;
}

//-----------------------------------------------------------------------------
static inline int DAP_CONFIG_nRESET_read(void)
{
  return HAL_GPIO_nRESET_read();
}

//-----------------------------------------------------------------------------
static inline void DAP_CONFIG_SWCLK_TCK_set(void)
{
  HAL_GPIO_SWCLK_TCK_set();
}

//-----------------------------------------------------------------------------
static inline void DAP_CONFIG_SWCLK_TCK_clr(void)
{
  HAL_GPIO_SWCLK_TCK_clr();
}

//-----------------------------------------------------------------------------
static inline void DAP_CONFIG_SWDIO_TMS_in(void)
{
  HAL_GPIO_SWDIO_TMS_in();
}

//-----------------------------------------------------------------------------
static inline void DAP_CONFIG_SWDIO_TMS_out(void)
{
  HAL_GPIO_SWDIO_TMS_out();
}

//-----------------------------------------------------------------------------
static inline void DAP_CONFIG_SETUP(void)
{
  HAL_GPIO_SWCLK_TCK_in();
  HAL_GPIO_SWDIO_TMS_in();
  HAL_GPIO_nRESET_in();
#ifdef DAP_CONFIG_ENABLE_JTAG
  HAL_GPIO_TDO_in();
  HAL_GPIO_TDI_in();
#endif
}
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

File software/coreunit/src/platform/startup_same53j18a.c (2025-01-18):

/*
 * GCC startup file for ATSAME53J18A
 *
 * Copyright (c) 2024 Microchip Technology Inc.  and its subsidiaries.
 *
 * Licensed under the Apache License, Version 2.0 (the "License");
 * you may not use this file except in compliance with the License.
 * You may obtain a copy of the License at
 *
 *   https://www.apache.org/licenses/LICENSE-2.0
 *
 * Unless required by applicable law or agreed to in writing, software
 * distributed under the License is distributed on an "AS IS" BASIS,
 * WITHOUT WARRANTIES OR CONDITIONS OF ANY KIND, either express or implied.
 * See the License for the specific language governing permissions and
 * limitations under the License.
 *
 */

#include "same53j18a.h"

/* Initialize segments */
extern uint32_t _sfixed;
extern uint32_t _efixed;
extern uint32_t _etext;
extern uint32_t _srelocate;
extern uint32_t _erelocate;
extern uint32_t _szero;
extern uint32_t _ezero;
extern uint32_t _sstack;
extern uint32_t _estack;

/* Optional application-provided functions */
extern void __attribute__((weak,long_call)) _on_reset(void);
extern void __attribute__((weak,long_call)) _on_bootstrap(void);
extern void __attribute__((weak,long_call)) _on_exit(void);

/** \cond DOXYGEN_SHOULD_SKIP_THIS */
int main(void);
/** \endcond */

void __libc_init_array(void);

/* Reset handler */
void Reset_Handler(void);

/* Default empty handler */
void Dummy_Handler(void);

/* Cortex-M4 core handlers */
void NonMaskableInt_Handler ( void ) __attribute__ ((weak, alias("Dummy_Handler")));
void HardFault_Handler    ( void ) __attribute__ ((weak, alias("Dummy_Handler")));
void MemoryManagement_Handler ( void ) __attribute__ ((weak, alias("Dummy_Handler")));
void BusFault_Handler     ( void ) __attribute__ ((weak, alias("Dummy_Handler")));
void UsageFault_Handler   ( void ) __attribute__ ((weak, alias("Dummy_Handler")));
void SVCall_Handler       ( void ) __attribute__ ((weak, alias("Dummy_Handler")));
void DebugMonitor_Handler ( void ) __attribute__ ((weak, alias("Dummy_Handler")));
void PendSV_Handler       ( void ) __attribute__ ((weak, alias("Dummy_Handler")));
void SysTick_Handler      ( void ) __attribute__ ((weak, alias("Dummy_Handler")));

/* Peripherals handlers */
void PM_Handler           ( void ) __attribute__ ((weak, alias("Dummy_Handler")));
void MCLK_Handler         ( void ) __attribute__ ((weak, alias("Dummy_Handler")));
void OSCCTRL_XOSC0_Handler ( void ) __attribute__ ((weak, alias("Dummy_Handler")));
void OSCCTRL_XOSC1_Handler ( void ) __attribute__ ((weak, alias("Dummy_Handler")));
void OSCCTRL_DFLL_Handler ( void ) __attribute__ ((weak, alias("Dummy_Handler")));
void OSCCTRL_DPLL0_Handler ( void ) __attribute__ ((weak, alias("Dummy_Handler")));
void OSCCTRL_DPLL1_Handler ( void ) __attribute__ ((weak, alias("Dummy_Handler")));
void OSC32KCTRL_Handler   ( void ) __attribute__ ((weak, alias("Dummy_Handler")));
void SUPC_OTHER_Handler   ( void ) __attribute__ ((weak, alias("Dummy_Handler")));
void SUPC_BODDET_Handler  ( void ) __attribute__ ((weak, alias("Dummy_Handler")));
void WDT_Handler          ( void ) __attribute__ ((weak, alias("Dummy_Handler")));
void RTC_Handler          ( void ) __attribute__ ((weak, alias("Dummy_Handler")));
void EIC_EXTINT_0_Handler ( void ) __attribute__ ((weak, alias("Dummy_Handler")));
void EIC_EXTINT_1_Handler ( void ) __attribute__ ((weak, alias("Dummy_Handler")));
void EIC_EXTINT_2_Handler ( void ) __attribute__ ((weak, alias("Dummy_Handler")));
void EIC_EXTINT_3_Handler ( void ) __attribute__ ((weak, alias("Dummy_Handler")));
void EIC_EXTINT_4_Handler ( void ) __attribute__ ((weak, alias("Dummy_Handler")));
void EIC_EXTINT_5_Handler ( void ) __attribute__ ((weak, alias("Dummy_Handler")));
void EIC_EXTINT_6_Handler ( void ) __attribute__ ((weak, alias("Dummy_Handler")));
void EIC_EXTINT_7_Handler ( void ) __attribute__ ((weak, alias("Dummy_Handler")));
void EIC_EXTINT_8_Handler ( void ) __attribute__ ((weak, alias("Dummy_Handler")));
void EIC_EXTINT_9_Handler ( void ) __attribute__ ((weak, alias("Dummy_Handler")));
void EIC_EXTINT_10_Handler ( void ) __attribute__ ((weak, alias("Dummy_Handler")));
void EIC_EXTINT_11_Handler ( void ) __attribute__ ((weak, alias("Dummy_Handler")));
void EIC_EXTINT_12_Handler ( void ) __attribute__ ((weak, alias("Dummy_Handler")));
void EIC_EXTINT_13_Handler ( void ) __attribute__ ((weak, alias("Dummy_Handler")));
void EIC_EXTINT_14_Handler ( void ) __attribute__ ((weak, alias("Dummy_Handler")));
void EIC_EXTINT_15_Handler ( void ) __attribute__ ((weak, alias("Dummy_Handler")));
void FREQM_Handler        ( void ) __attribute__ ((weak, alias("Dummy_Handler")));
void NVMCTRL_0_Handler    ( void ) __attribute__ ((weak, alias("Dummy_Handler")));
void NVMCTRL_1_Handler    ( void ) __attribute__ ((weak, alias("Dummy_Handler")));
void DMAC_0_Handler       ( void ) __attribute__ ((weak, alias("Dummy_Handler")));
void DMAC_1_Handler       ( void ) __attribute__ ((weak, alias("Dummy_Handler")));
void DMAC_2_Handler       ( void ) __attribute__ ((weak, alias("Dummy_Handler")));
void DMAC_3_Handler       ( void ) __attribute__ ((weak, alias("Dummy_Handler")));
void DMAC_OTHER_Handler   ( void ) __attribute__ ((weak, alias("Dummy_Handler")));
void EVSYS_0_Handler      ( void ) __attribute__ ((weak, alias("Dummy_Handler")));
void EVSYS_1_Handler      ( void ) __attribute__ ((weak, alias("Dummy_Handler")));
void EVSYS_2_Handler      ( void ) __attribute__ ((weak, alias("Dummy_Handler")));
void EVSYS_3_Handler      ( void ) __attribute__ ((weak, alias("Dummy_Handler")));
void EVSYS_OTHER_Handler  ( void ) __attribute__ ((weak, alias("Dummy_Handler")));
void PAC_Handler          ( void ) __attribute__ ((weak, alias("Dummy_Handler")));
void RAMECC_Handler       ( void ) __attribute__ ((weak, alias("Dummy_Handler")));
void SERCOM0_0_Handler    ( void ) __attribute__ ((weak, alias("Dummy_Handler")));
void SERCOM0_1_Handler    ( void ) __attribute__ ((weak, alias("Dummy_Handler")));
void SERCOM0_2_Handler    ( void ) __attribute__ ((weak, alias("Dummy_Handler")));
void SERCOM0_OTHER_Handler ( void ) __attribute__ ((weak, alias("Dummy_Handler")));
void SERCOM1_0_Handler    ( void ) __attribute__ ((weak, alias("Dummy_Handler")));
void SERCOM1_1_Handler    ( void ) __attribute__ ((weak, alias("Dummy_Handler")));
void SERCOM1_2_Handler    ( void ) __attribute__ ((weak, alias("Dummy_Handler")));
void SERCOM1_OTHER_Handler ( void ) __attribute__ ((weak, alias("Dummy_Handler")));
void SERCOM2_0_Handler    ( void ) __attribute__ ((weak, alias("Dummy_Handler")));
void SERCOM2_1_Handler    ( void ) __attribute__ ((weak, alias("Dummy_Handler")));
void SERCOM2_2_Handler    ( void ) __attribute__ ((weak, alias("Dummy_Handler")));
void SERCOM2_OTHER_Handler ( void ) __attribute__ ((weak, alias("Dummy_Handler")));
void SERCOM3_0_Handler    ( void ) __attribute__ ((weak, alias("Dummy_Handler")));
void SERCOM3_1_Handler    ( void ) __attribute__ ((weak, alias("Dummy_Handler")));
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

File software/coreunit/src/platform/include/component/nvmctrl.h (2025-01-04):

/*
 * Component description for NVMCTRL
 *
 * Copyright (c) 2024 Microchip Technology Inc. and its subsidiaries.
 *
 * Licensed under the Apache License, Version 2.0 (the "License");
 * you may not use this file except in compliance with the License.
 * You may obtain a copy of the License at
 *
 *   http://www.apache.org/licenses/LICENSE-2.0
 *
 * Unless required by applicable law or agreed to in writing, software
 * distributed under the License is distributed on an "AS IS" BASIS,
 * WITHOUT WARRANTIES OR CONDITIONS OF ANY KIND, either express or implied.
 * See the License for the specific language governing permissions and
 * limitations under the License.
 *
 */

/* file generated from device description file (ATDF) version 2023-03-17T09:50:04Z */
#ifndef _SAME53_NVMCTRL_COMPONENT_H_
#define _SAME53_NVMCTRL_COMPONENT_H_

/* ************************************************************************** */
/*   SOFTWARE API DEFINITION FOR NVMCTRL                                      */
/* ************************************************************************** */

/* -------- NVMCTRL_CTRLA : (NVMCTRL Offset: 0x00) (R/W 16) Control A -------- */
#define NVMCTRL_CTRLA_RESETVALUE              _UINT16_(0x04)                                       /*  (NVMCTRL_CTRLA) Control A  Reset Value */

#define NVMCTRL_CTRLA_AUTOWS_Pos              _UINT16_(2)                                          /* (NVMCTRL_CTRLA) Auto Wait State Enable Position */
#define NVMCTRL_CTRLA_AUTOWS_Msk              (_UINT16_(0x1) << NVMCTRL_CTRLA_AUTOWS_Pos)          /* (NVMCTRL_CTRLA) Auto Wait State Enable Mask */
#define NVMCTRL_CTRLA_AUTOWS(value)           (NVMCTRL_CTRLA_AUTOWS_Msk & (_UINT16_(value) << NVMCTRL_CTRLA_AUTOWS_Pos)) /* Assigment of value for AUTOWS in the NVMCTRL_CTRLA register */
#define NVMCTRL_CTRLA_SUSPEN_Pos              _UINT16_(3)                                          /* (NVMCTRL_CTRLA) Suspend Enable Position */
#define NVMCTRL_CTRLA_SUSPEN_Msk              (_UINT16_(0x1) << NVMCTRL_CTRLA_SUSPEN_Pos)          /* (NVMCTRL_CTRLA) Suspend Enable Mask */
#define NVMCTRL_CTRLA_SUSPEN(value)           (NVMCTRL_CTRLA_SUSPEN_Msk & (_UINT16_(value) << NVMCTRL_CTRLA_SUSPEN_Pos)) /* Assigment of value for SUSPEN in the NVMCTRL_CTRLA register */
#define NVMCTRL_CTRLA_WMODE_Pos               _UINT16_(4)                                          /* (NVMCTRL_CTRLA) Write Mode Position */
#define NVMCTRL_CTRLA_WMODE_Msk               (_UINT16_(0x3) << NVMCTRL_CTRLA_WMODE_Pos)           /* (NVMCTRL_CTRLA) Write Mode Mask */
#define NVMCTRL_CTRLA_WMODE(value)            (NVMCTRL_CTRLA_WMODE_Msk & (_UINT16_(value) << NVMCTRL_CTRLA_WMODE_Pos)) /* Assigment of value for WMODE in the NVMCTRL_CTRLA register */
#define   NVMCTRL_CTRLA_WMODE_MAN_Val         _UINT16_(0x0)                                        /* (NVMCTRL_CTRLA) Manual Write  */
#define   NVMCTRL_CTRLA_WMODE_ADW_Val         _UINT16_(0x1)                                        /* (NVMCTRL_CTRLA) Automatic Double Word Write  */
#define   NVMCTRL_CTRLA_WMODE_AQW_Val         _UINT16_(0x2)                                        /* (NVMCTRL_CTRLA) Automatic Quad Word  */
#define   NVMCTRL_CTRLA_WMODE_AP_Val          _UINT16_(0x3)                                        /* (NVMCTRL_CTRLA) Automatic Page Write  */
#define NVMCTRL_CTRLA_WMODE_MAN               (NVMCTRL_CTRLA_WMODE_MAN_Val << NVMCTRL_CTRLA_WMODE_Pos) /* (NVMCTRL_CTRLA) Manual Write Position  */
#define NVMCTRL_CTRLA_WMODE_ADW               (NVMCTRL_CTRLA_WMODE_ADW_Val << NVMCTRL_CTRLA_WMODE_Pos) /* (NVMCTRL_CTRLA) Automatic Double Word Write Position  */
#define NVMCTRL_CTRLA_WMODE_AQW               (NVMCTRL_CTRLA_WMODE_AQW_Val << NVMCTRL_CTRLA_WMODE_Pos) /* (NVMCTRL_CTRLA) Automatic Quad Word Position  */
#define NVMCTRL_CTRLA_WMODE_AP                (NVMCTRL_CTRLA_WMODE_AP_Val << NVMCTRL_CTRLA_WMODE_Pos) /* (NVMCTRL_CTRLA) Automatic Page Write Position  */
#define NVMCTRL_CTRLA_PRM_Pos                 _UINT16_(6)                                          /* (NVMCTRL_CTRLA) Power Reduction Mode during Sleep Position */
#define NVMCTRL_CTRLA_PRM_Msk                 (_UINT16_(0x3) << NVMCTRL_CTRLA_PRM_Pos)             /* (NVMCTRL_CTRLA) Power Reduction Mode during Sleep Mask */
#define NVMCTRL_CTRLA_PRM(value)              (NVMCTRL_CTRLA_PRM_Msk & (_UINT16_(value) << NVMCTRL_CTRLA_PRM_Pos)) /* Assigment of value for PRM in the NVMCTRL_CTRLA register */
#define   NVMCTRL_CTRLA_PRM_SEMIAUTO_Val      _UINT16_(0x0)                                        /* (NVMCTRL_CTRLA) NVM block enters low-power mode when entering standby mode. NVM block enters low-power mode when SPRM command is issued. NVM block exits low-power mode upon first access.  */
#define   NVMCTRL_CTRLA_PRM_FULLAUTO_Val      _UINT16_(0x1)                                        /* (NVMCTRL_CTRLA) NVM block enters low-power mode when entering standby mode. NVM block enters low-power mode when SPRM command is issued. NVM block exits low-power mode when system is not in standby mode.  */
#define   NVMCTRL_CTRLA_PRM_MANUAL_Val        _UINT16_(0x3)                                        /* (NVMCTRL_CTRLA) NVM block does not enter low-power mode when entering standby mode. NVM block enters low-power mode when SPRM command is issued. NVM block exits low-power mode upon first access.  */
#define NVMCTRL_CTRLA_PRM_SEMIAUTO            (NVMCTRL_CTRLA_PRM_SEMIAUTO_Val << NVMCTRL_CTRLA_PRM_Pos) /* (NVMCTRL_CTRLA) NVM block enters low-power mode when entering standby mode. NVM block enters low-power mode when SPRM command is issued. NVM block exits low-power mode upon first access. Position  */
#define NVMCTRL_CTRLA_PRM_FULLAUTO            (NVMCTRL_CTRLA_PRM_FULLAUTO_Val << NVMCTRL_CTRLA_PRM_Pos) /* (NVMCTRL_CTRLA) NVM block enters low-power mode when entering standby mode. NVM block enters low-power mode when SPRM command is issued. NVM block exits low-power mode when system is not in standby mode. Position  */
#define NVMCTRL_CTRLA_PRM_MANUAL              (NVMCTRL_CTRLA_PRM_MANUAL_Val << NVMCTRL_CTRLA_PRM_Pos) /* (NVMCTRL_CTRLA) NVM block does not enter low-power mode when entering standby mode. NVM block enters low-power mode when SPRM command is issued. NVM block exits low-power mode upon first access. Position  */
#define NVMCTRL_CTRLA_RWS_Pos                 _UINT16_(8)                                          /* (NVMCTRL_CTRLA) NVM Read Wait States Position */
#define NVMCTRL_CTRLA_RWS_Msk                 (_UINT16_(0xF) << NVMCTRL_CTRLA_RWS_Pos)             /* (NVMCTRL_CTRLA) NVM Read Wait States Mask */
#define NVMCTRL_CTRLA_RWS(value)              (NVMCTRL_CTRLA_RWS_Msk & (_UINT16_(value) << NVMCTRL_CTRLA_RWS_Pos)) /* Assigment of value for RWS in the NVMCTRL_CTRLA register */
#define NVMCTRL_CTRLA_AHBNS0_Pos              _UINT16_(12)                                         /* (NVMCTRL_CTRLA) Force AHB0 access to NONSEQ, burst transfers are continuously rearbitrated Position */
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

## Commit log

2024-09-14 added CAD file with one face started
    [cubitron.FCStd]
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2024-09-15 Further progress on flywheel
    [cubitron.FCStd]
2024-09-15 IMU Chip first draft, just needs to be looked over by someone
    [cubitron.FCStd, imu_IC.kicad_pcb, imu_IC.kicad_sch]
2024-09-16 Rounded corners, removed pin symbol noise
    [imu_IC.kicad_pcb]
2024-09-16 updated docs and added motordriver pcb
    [controller.kicad_pcb, controller.kicad_sch, motordriver.kicad_pcb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]
2024-09-16 updated readme and restructured
    [cubitron.FCStd, imu_IC.kicad_pcb, imu_IC.kicad_sch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]
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2024-09-16 fixed imu pcb offset
2024-09-16 Removed kicad folder, replaced with PCB folder
    [controller.kicad_pcb, controller.kicad_sch, motordriver.kicad_pcb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]
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2024-09-24 updated motordriver and gitignore to not track backups
    [brakectrl.kicad_sch, currentsense.kicad_sch, driverIC.kicad_sch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]
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2024-09-28 Adjusted tolerances based on physical measurements
    [cubitron.FCStd]
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2024-10-11 moved controller pcb to a single unified pcb, added more work on motordriver
    [controller.kicad_pcb, controller.kicad_sch, gates.kicad_sch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]
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2024-10-19 cortex added, fixed some symbols in motordriver file
    [driverIC.kicad_sch, microcontroller.kicad_sch]
2024-10-19 fixed merge
    [driverIC.kicad_sch]
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2024-10-24 USB-C schematics to programmer, programmer to cortex-4 added
    [driverIC.kicad_sch, programmer.kicad_sch]
2024-10-24 First draft of programmer added. GPIO pins are axed atm but can be included if we want some extra functionality, like indicator LEDs or similar.
    Routing from USB-C to programmer to main cortex are added. Also
    added some datasheets and sources.
    [microcontroller.kicad_sch, programmer.kicad_sch]
2024-10-25 12 to 3.3 LDO added, temporary 5 to 12 reg added
    [EDI2CAP.CFG, LD1117S33CTR.step, MC34063ECD-TR.SchLib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]
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2024-10-28 5V ref IC changed to correct one
    [EDI2CAP.CFG, REF3450TIDBVR.SchLib, REF3450TIDBVR.stp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]
2024-10-31 Clearer file names for datasheets indicating what kind of component they are. Started on connecting the battery charger Added mosfet ICs for driver gates
    [EDI2CAP.CFG, SI4532CDY-T1-GE3.SchLib, SI4532CDY-T1-GE3.stp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]
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2024-11-02 fixed schematic layout and added shunt resistor and zener diodes for motor stage
    [currentsense.kicad_sch, gates.kicad_sch, input.kicad_sch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]
2024-11-03 added lables and worked on the motor stage, changed the mosfet driver
    [LM5109BSDX_NOPB.stp, driverIC.kicad_sch, gates.kicad_sch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]
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2024-11-07 drove up some hierarchial connections in root sheet
    [gates.kicad_sch, motordriver.kicad_sch]
2024-11-09 added oled header and connected to microcontroller. progress on vreg
    [microcontroller.kicad_sch, output.kicad_sch, voltageregulatros.kicad_sch]
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2024-11-10 This battery charger is killing me.
    Completed 8/24 pins
    Following are completed:
    VREF
    TTC
    TS
    STAT
    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
    [voltageregulatros.kicad_sch]
2024-11-11 added correct analog voltage lables
    [driverIC.kicad_sch, voltageregulatros.kicad_sch]
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2024-11-16 Added micro-servo headers Added header for FFC cable IMU PCB
    We need to set IMU PCB input to correspond to
    the one we have made here.
    [59453-052110ECHLF.SchLib, 59453-052110ECHLF.stp, 59453-061110ECHLF.SchLib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]
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2024-11-17 worked on power and merged programmer and microcontroller sheets
    [currentsense.kicad_sch, driverIC.kicad_sch, gates.kicad_sch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]
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2024-11-18 finished 12v voltage, The components for alost all ICs need values. Cleaned up a bit
    [INA2181A2IDGSR.stp, driverIC.kicad_sch, gates.kicad_sch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]
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2024-12-11 Removed unneccessary TMC4761 pins
    Finally went through every pin on the TMC and tried to eliminate
    unneeded pins. Reduced sheet complexity quite nicely. Pretty much
    all rationales for removing pins were added to the design document,
    although not formatted that nicely yet.
    [driverIC.kicad_sch, microcontrollers.kicad_sch, motordriver.kicad_sch]
2024-12-12 Switched TMC hall sensor input to digital from motors
    [driverIC.kicad_sch, microcontrollers.kicad_sch, motordriver.kicad_sch]
2024-12-12 TMC and MCU connections
    Further progress on PCB. Main remainders are:
    Voltage regulator page (couple todos)
    Fix sheet duplication for output sheets
    Decide on UART or SPI debug for TMC
    Formalize stuff, fill out bottom right on sheets
    [driverIC.kicad_sch, microcontrollers.kicad_sch, motordriver.kicad_sch]
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2024-12-16 fixed references
    [IO.kicad_sch, driverIC.kicad_sch, gates.kicad_sch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]
2024-12-18 new footprint and symbol system. added more footprints
    [1-84952-1.stp, 59453-052110ECHLF.stp, 59453-061110ECHLF.stp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]
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2024-12-20 Started on software
    State machine structure is laid out.
    TMC4671 drivers are taken from official software.
    IMU drivers are taken from portalspace/drivers, but are
    not fully configured for our purposes yet.
    Compact Quaternion library has also been added.
    [motordriver.kicad_pcb]
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2024-12-22 removed backup files and found components for special resistors and diodes
    [IO.kicad_sch, RCL122510R0FKEG.stp, SL44HE3_B_I.stp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]
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2024-12-23 fixed root folder schematics
    [driverIC.kicad_sch, microcontrollers.kicad_sch, motordriver.kicad_sch]
2024-12-23 Double checked all SERCOM pins
    Finally looked at how SERCOMs work in this chip, what the PADs
    mean and so on. This allowed me to double check all communication
    pins and make sure all communication between modules are on correct
    peripherals.
    [microcontrollers.kicad_sch]
2024-12-23 MCU connections double checked/fixed
    Made sure all individual communication lines happens
    on their own SERCOM instance. Made sure all PWM signals are on
    PWM compatible pins, same for interrupts.
    [microcontrollers.kicad_sch]
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2024-12-23 tmc gpio pins fixed, spi db fixed, all mcu digital pins fixed, decoupled resetn
    [IO.kicad_sch, microcontrollers.kicad_sch, motordriver.kicad_sch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]
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2024-12-23 double checked SERCOM again, as well as PWM and interrupt pin capabilities
    [microcontrollers.kicad_sch, motordriver.kicad_sch]
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2024-12-27 minor tweaks on schematic and started on the pcb layout, made good work
    [IO.kicad_sch, XT60-M.step, gates.kicad_sch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]
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2025-01-05 added design rules from pcbway, we need to redo some work to fit the design rules
    [IO.kicad_sch, gates.kicad_sch, microcontrollers.kicad_sch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]
2025-01-06 added external oscillator files
    [DSC6001CI2B-025.0000T.stp]
2025-01-07 pre rework of pwr planes to save if something goes wrong
    [motordriver.kicad_pcb]
2025-01-07 sw and hw lmao
    worked on drivers mainly. added oscillator to schematic.
    [microcontrollers.kicad_sch]
2025-01-07 layout rework, better ground plane
    [motordriver.kicad_pcb, motordriver.kicad_sch]
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2025-01-10 worked on pcb and added led to programmer and jumpers to swd line
    [gates.kicad_sch, microcontrollers.kicad_sch, motorIO.kicad_sch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]
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2025-01-18 dap software compiles, need to be configured correctly tho
    [ac.h, adc.h, aes.h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]
2025-01-19 worked on cmsis dap implementation aswell as cleaned up startup files for both microcontrolers
    [IO.kicad_sch, gates.kicad_sch, microcontrollers.kicad_sch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]
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2025-01-26 added new brake chopper logic, the previous was sketchy, still we might need to find better brake resistors than the one I added
    [IO.kicad_sch, PWR263S-20-10R0F.stp, brake.kicad_sch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]
2025-02-21 motor holder progress, need 2 add fastening point
    [200142_EC45fl_30W_A.stp, flywheel.FCStd, motor_holder.FCStd]
2025-02-21 shaft hub started. unsure of screw holes mainly
    [shaft_hub.FCStd]
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2025-03-05 Motor holder fastening
    Added correct length from center of motor holder
    to edge of cube. Added holes in correct place. As
    well
    The thickness of the cube will probably have to be adjusted.
    I do not have the energy to find out how to flip them in
    the assembly. The "cube" is pointing the wrong way.
    [motor.FCStd]
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2025-03-08 removed pullup resistor on swdio as it is too small
    [microcontrollers.kicad_sch]
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
